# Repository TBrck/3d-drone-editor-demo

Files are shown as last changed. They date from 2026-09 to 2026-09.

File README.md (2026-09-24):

# AeroFrame X1

A 450 mm quadcopter airframe, designed parametrically in Python and published
as an interactive web page you can rotate, explode and take apart in a
browser.

**[Open the interactive model →](https://tbrockmeyer.github.io/3d-drone-editor-demo/)**
*(link goes live once GitHub Pages is enabled on this repo)*

---

## What this is

A mechanical design study. Every part was modelled in code on the OpenCASCADE
kernel; every mass, stress and safety factor shown on the site was computed
from that same geometry rather than typed in. Change one number in
[config.py](src/drone_demo/config.py) and the model, the bill of materials,
the drawings and the analysis all regenerate together.

The airframe is deliberately built from six different manufacturing processes,
one per part family, so the design decisions behind each are visible:

| Part | Process | Material |
|---|---|---|
| Motor mounts, arm clamps | CNC milling | Al 6061-T6 |
| Frame plates | CFRP sheet, CNC routed | 2 mm woven laminate |
| Arm tubes | Pultruded stock, cut to length | CFRP |
| ESC brackets, battery tray | Sheet metal, laser + press brake | Al 5052-H32 |
| Landing legs | FDM 3D printing | PA12-CF |
| Feet, propellers | Injection moulding | TPU / PA6-GF30 |

## What the site shows

- The full assembly, orbitable, with an exploded-view slider and a section plane
- Click any part for its material, process, mass, tolerances and the reasoning behind its design
- A bill of materials with the mass breakdown
- Hand calculations — arm root bending, tip deflection, first natural frequency, clamp slip, bolt shear, landing impact — each shown with its formula and inputs
- Linear-static FEA results overlaid on the model, with a mesh convergence check and a plain statement of the method's limits
- Dimensioned drawings and downloadable STEP files

---

## Quick start — just look at it

You do **not** need to rebuild anything to view the model: the generated
`drone.glb`, `manifest.json`, drawings and STEP files are already committed
under `web/assets/`. All you need is Python 3.11 to serve them (the CAD
kernel is not required just to view the page — only to change it).

```powershell
.\scripts\bootstrap.ps1                  # one-time: creates .venv311, installs everything
python -m drone_demo serve               # serves web/ and opens it in your browser
```

`bootstrap.ps1` also activates nothing on its own — after it finishes, either
activate the venv (`.venv311\Scripts\Activate.ps1`, after which plain `python`
means the venv's Python) or call the interpreter directly every time:

```powershell
.venv311\Scripts\python.exe -m drone_demo serve
```

Both `python -m drone_demo <command>` and `python src/drone_demo <command>`
work identically — pick whichever you find more natural. `serve` opens
`http://127.0.0.1:8000` in your default browser automatically; pass
`--port 8080` or `--no-open-browser` if you want something different.

> **The page must be served over HTTP.** Double-clicking `web/index.html`
> will not work — it loads `manifest.json` and `drone.glb` via `fetch()` and
> uses ES modules, both of which browsers block on `file://` URLs.

---

## Making a change

Everything downstream is *derived*, never hand-edited. The one-way flow is:

```
config.py + materials.py     the specification — every dimension, one file
        |
        v
parts/*.py                   geometry builders — one file per sub-assembly
        |
        v
assembly.py                  where each part instance is placed, and how many
        |
        +--> analysis/       mass properties, hand calculations, FEA
        |
        v
export/                      writes drone.glb, manifest.json, SVG, STEP, DXF
        |
        v
web/                          the site — reads manifest.json, has no design data of its own
```

That last point matters: the browser never contains a dimension, a mass or a
material property directly. It only reads whatever `export/manifest.py`
wrote. So changing the design is always the same three steps: **edit the
Python, regenerate the assets, refresh the browser.**

### 1. Change a dimension

Every physical dimension in the airframe lives in one file:
[`src/drone_demo/config.py`](src/drone_demo/config.py). It's a set of frozen
dataclasses, one per sub-assembly, assembled into a single `SPEC` object that
the rest of the codebase imports and never mutates.

For example, to make the vehicle bigger, open `config.py` and find the
`Airframe` dataclass near the top:

```python
@dataclass(frozen=True)
class Airframe:
    ...
    wheelbase_mm: float = 450.0   # <- change this to 550.0, say
```

Then rebuild just the geometry (fast — tens of seconds, no FEA) and refresh
the already-open browser tab:

```powershell
python -m drone_demo build
```

If `serve` is still running in another terminal, a browser refresh is all you
need — `build` overwrites `web/assets/drone.glb` and `manifest.json` in
place.

Other dataclasses worth knowing:

| Dataclass | Controls |
|---|---|
| `Airframe` | wheelbase, arm count, arm angle, target mass, thrust target |
| `ArmTube`, `MotorMount`, `ArmClamp` | the arm assembly |
| `FramePlate`, `Standoff` | the top/bottom plates and how they're spaced |
| `LandingLeg`, `LandingFoot` | the printed leg and moulded foot |
| `EscBracket`, `BatteryTray` | the two sheet-metal parts |
| `Motor`, `Propeller`, `Battery` | purchased-item envelopes (for mass and clearance only — not designed here) |

A few dimensions are cross-checked by tests (for example `ArmTube.length_mm`
has to keep the arm's tube+collar geometry landing exactly on the wheelbase
radius). If you change something load-bearing, run `pytest` afterward (see
below) — it will tell you exactly which geometric consistency check broke,
rather than letting the model silently go out of tolerance.

### 2. Change a shape

Dimensions alone only get you so far — actually changing *what a part looks
like* means editing its builder function in
[`src/drone_demo/parts/`](src/drone_demo/parts/). There's one file per
sub-assembly:

| File | Parts it builds |
|---|---|
| `arm.py` | arm tube, motor mount, split clamp halves |
| `frame.py` | top/bottom plates, standoffs |
| `landing.py` | landing leg, landing foot |
| `electronics.py` | ESC bracket, battery tray, motor/battery placeholder solids |
| `rotor.py` | propeller |
| `hardware.py` | screws |

Each part is a small, self-contained function that returns a
`build123d.Part`, built with build123d's `BuildPart`/`BuildSketch` context
managers (the same declarative style as most modern Python CAD kernels — see
[build123d's docs](https://build123d.readthedocs.io/) if you haven't used it
before). At the bottom of each file, one `register(PartDef(...))` call wires
the builder into the pipeline — that's the part's key, its name, which
material/process it uses, how many the assembly needs, and the design notes
shown in the viewer's detail panel. `src/drone_demo/parts/base.py` documents
every `PartDef` field.

To **add a brand-new part**: write a builder function, `register()` it with
a new unique key, and import the module (for its side effect of calling
`register()`) from [`parts/__init__.py`](src/drone_demo/parts/__init__.py).
Nothing else in the pipeline needs to know — mass, BOM, drawings and the
viewer all discover parts by walking the registry.

### 3. Change where a part is placed

How many instances of a part exist, and where each one sits in the assembly,
is decided in [`assembly.py`](src/drone_demo/assembly.py) — not in the part's
own builder, which only ever describes the part in its own local coordinate
frame. If you add a part and it isn't showing up anywhere (or four of
something show up stacked on top of each other), this is the file to look at.

### 4. Rebuild and check your work

```powershell
python -m drone_demo build       # geometry only -> drone.glb + manifest.json (fast: iterate here)
python -m drone_demo analyse     # print mass properties + hand calcs to the console
python -m drone_demo all         # full pipeline: geometry, FEA, drawings, downloads, manifest (slow: a few minutes)
pytest                            # run the test suite (add -m "not slow" to skip the CAD-rebuild tests)
```

Run `build` while you iterate on a shape or dimension — it's the fast loop.
Run `all` once, right before you're done, since it's the only command that
regenerates *everything* the published page depends on (including the FEA
results and STEP downloads, which `build` intentionally skips because they
take minutes). `pytest` catches the two failure modes that are easy to
introduce by hand and hard to spot by eye: parts that now interfere in 3D,
and a "parametric" model that only actually builds at its default dimensions.

---

## Parts & assembly studio

A local, login-gated web app for creating **simple** new parts — box/
cylinder/sphere plus union/subtract/intersect and rigid transforms — and
placing them in the vehicle, either by dragging primitives in a 3D editor or
by hand-editing JSON. It's a separate tool from the published site: it needs
its own dependency and never ships to GitHub Pages.

```powershell
pip install -e ".[studio]"      # one-time: installs Flask
python -m drone_demo studio     # http://127.0.0.1:5000, admin/admin (dummy — local only)
```

Everything a studio part needs — its shape, material, placement — lives in
[`src/drone_demo/custom_parts.json`](src/drone_demo/custom_parts.json), a
plain JSON file. The studio UI is one way to edit it; hand-editing the file
directly works exactly the same, since both go through the same
[`build_from_shape_spec`](src/drone_demo/parts/custom.py) interpreter — there
is no separate "studio path" a hand-written part takes that produces a
different result. A studio part becomes an ordinary `PartDef`/`Instance` the
moment `custom_parts.json` has an entry for it, so it flows through mass
properties, the BOM, `manifest.json` and STEP export with no other code
involved.

This complements, not replaces, the parametric workflow above: anything
needing a fillet, a loft, a chamfer or a sweep — most of what's actually on
this airframe — stays a hand-written `build123d` function, the same as
today. The studio is for the simple stuff (a spacer, a mounting plate, a
bracket) you'd rather sketch than write a `BuildPart` block for.

A saved change updates `custom_parts.json` immediately, but the read-only
assembly shown behind the part you're editing, and the actual published
site, only update when you rebuild — either the studio's own "Rebuild"
button, or `python -m drone_demo build` from the terminal.

**Honestly not production-grade, on purpose**: the login is a single
hardcoded credential (`admin`/`admin`), checked by one function
([`drone_demo.studio.auth.verify_credentials`](src/drone_demo/studio/auth.py))
that everything else calls through — swapping in a real user store later is
a one-function change, not a rewrite. It's fine as-is because the studio only
ever binds to `127.0.0.1`, exactly like `serve`.

---

## Project layout

```
src/drone_demo/
  config.py          every dimension — the one file to edit for a resize
  materials.py        material properties (density, yield) and process metadata
  custom_parts.json     studio-authored parts — see "Parts & assembly studio" above
  parts/               one module per sub-assembly; each part is a PartDef
    base.py            the PartDef contract every part module satisfies
    custom.py           reads custom_parts.json, interprets shape JSON into build123d
  assembly.py          instance placement: how many of each part, and where
  analysis/
    mass_properties.py  mass, centre of gravity, inertia
    statics.py          closed-form hand calculations
    fea.py               gmsh meshing + scikit-fem finite element solves
  export/
    gltf.py              writes drone.glb for the web viewer
    manifest.py          writes manifest.json, the contract with web/
    drawings.py           dimensioned SVG sheets + DXF flat patterns
    cad.py                STEP/STL downloads
  studio/                Flask app behind `python -m drone_demo studio` (needs the studio extra)
  cli.py                the `drone_demo` command line app
web/
  index.html, css/, js/  the static viewer (three.js) — reads manifest.json only
  vendor/                 vendored, pinned three.js (not from a CDN)
  assets/                  generated output: drone.glb, manifest.json, drawings/, downloads/, fea/
studio/
  templates/, static/     the studio's own frontend — deliberately not under web/,
                           since web/ is what ships to the public GitHub Pages site
docs/
  IMPLEMENTATION_PLAN.md  build order, specifications, acceptance criteria
tests/                    pytest suite — geometry, interference, manifest contract
```

## CLI reference

```powershell
python -m drone_demo --help     # full command list
python -m drone_demo parts      # list the part registry
python -m drone_demo check      # sanity-check every builder still runs
python -m drone_demo build      # geometry -> drone.glb + manifest.json (fast, for iteration)
python -m drone_demo analyse    # print mass properties and the hand calculations
python -m drone_demo fea        # finite element cases (slow, a few minutes)
python -m drone_demo drawings   # SVG sheets and DXF flat patterns
python -m drone_demo downloads  # STEP/STL/DXF download set
python -m drone_demo all        # everything above, in order, into one manifest
python -m drone_demo serve      # http://127.0.0.1:8000
python -m drone_demo studio     # http://127.0.0.1:5000 — parts & assembly studio, needs pip install -e ".[studio]"
```

---

## Troubleshooting

**The page loads (header and side panel look right) but the 3D viewport is
solid black.** This is almost always the browser's WebGL context, not the
generated model — nothing in `web/assets/` differs between a working and a
black viewport. Check, in order:
1. Open DevTools (F12) → Console while on the Model tab and look for a red
   error mentioning `WebGLRenderer` or `CONTEXT_LOST`. That error message is
   the actual cause.
2. In Chrome/Edge, open `chrome://gpu` (or `edge://gpu`) and check the
   "Graphics Feature Status" section for `WebGL`/`WebGL2`. If it says
   "Software only" or lists it as disabled, hardware acceleration is off —
   re-enable it under Settings → System, or check with IT if this is a
   managed machine (common on corporate/VDI images).
3. Hard-refresh (Ctrl+Shift+R) to rule out a stale cached `drone.glb` from
   before a rebuild.

**`ModuleNotFoundError` when running a command.** Every intra-package import
in `src/drone_demo` is a fully-qualified `drone_demo.xyz` absolute import, so
`python -m drone_demo ...`, `python src/drone_demo ...` and the installed
`drone-demo` console script all work identically — this only breaks if the
package isn't installed in your active interpreter. Re-run
`.\scripts\bootstrap.ps1`, or check `python -c "import drone_demo; print(drone_demo.__file__)"`
resolves to this repo's `src/drone_demo/`.

**Port 8000 already in use.** `python -m drone_demo serve --port 8080`.

---

## Documentation

- [docs/IMPLEMENTATION_PLAN.md](docs/IMPLEMENTATION_PLAN.md) — build order, specifications, acceptance criteria

## Limitations

Stated plainly, because a design study that oversells its analysis is worse
than one that has none:

- FEA is linear-static on first-order tetrahedra: a screening and comparison
  tool, not a certification analysis.
- Bolted joints are fixed restraints. No contact, preload or friction.
- Composites are treated as isotropic — reasonable for the tube in axial
  bending, wrong elsewhere.
- Endurance is a first-order energy estimate, good to perhaps 20 %.
- Nothing here has been built or flown.

## Licence

MIT.

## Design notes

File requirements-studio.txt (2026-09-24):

# Extra dependency for the parts & assembly studio (`python -m drone_demo
# studio`), pinned to the version installed and smoke-tested in .venv311
# (Python 3.11.7, Windows 11). Not part of requirements.txt: the studio is a
# local, login-gated authoring tool, not part of the published pipeline, so
# the core CAD/CLI workflow's dependency footprint stays untouched without
# this file. Install with:
#
#     .venv311\Scripts\python.exe -m pip install -r requirements.txt -r requirements-studio.txt
#     .venv311\Scripts\python.exe -m pip install -e ".[studio]"

flask==3.1.3

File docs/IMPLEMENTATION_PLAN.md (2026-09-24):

# AeroFrame X1 — implementation plan

This document is written to be handed to someone (or something) that will
write the code. The scaffolding, the specification, the part registry, the
engineering rationale and the file layout already exist in the repo. What is
missing is geometry, arithmetic and rendering.

Every stub in the codebase points back here with a step number. Every step
below states what to build, how to know it works, and what to avoid.

---

## 0. How to use this plan

**Read this first, then work milestone by milestone.** The milestones in
[§10](#10-milestones) are ordered so that something is visible on screen
early and stays working. Do not implement the whole pipeline before running
anything — the failure modes in CAD code are geometric, and geometric bugs
are found by looking.

**Rules that apply everywhere:**

1. **No hard-coded dimensions outside `config.py`.** If a number appears in a
   part module, it is a bug. The one exception is a genuinely universal
   constant (`math.pi`), and even then prefer a named constant.
2. **No design strings in JavaScript.** All display text comes from
   `manifest.json`. A number typed into the web layer stops matching the CAD
   the first time a parameter changes, and nothing will warn you.
3. **Units are mm, grams, newtons, MPa** throughout Python. The only unit
   conversion in the codebase is in `export/gltf.py`, which converts to
   metres because glTF requires it.
4. **Select CAD features by position, never by index.** `edges()[3]` works
   until a dimension changes and then silently fillets the wrong edge.
   Use `.filter_by()`, `.group_by(Axis.Z)`, `.sort_by()` with a geometric
   predicate.
5. **Run the tests after every part.** `pytest -m "not slow"` takes about
   four seconds and catches most parameter mistakes.
6. **When a stub's docstring and this document disagree, the docstring
   wins** — it is closer to the code.

---

## 1. Environment — already done and verified

`.venv311` exists and is provisioned. Python 3.11.7 on Windows. Every package
below installed cleanly and was smoke-tested end to end on this machine:

| Package | Version | Role |
|---|---|---|
| `build123d` | 0.11.1 | CAD kernel wrapper (pulls `cadquery-ocp-novtk` 7.9.3) |
| `trimesh` | 5.0.0 | mesh handling, GLB writing |
| `numpy` | 2.4.6 | arrays |
| `scipy` | 1.17.1 | sparse solver behind scikit-fem |
| `gmsh` | 4.15.2 | tetrahedral meshing; the wheel bundles the binary |
| `scikit-fem` | 12.0.2 | FE assembly and solve |
| `meshio` | 5.3.5 | `.msh` reader |
| `typer` / `rich` | 0.27.1 / 15.0.0 | CLI |
| `pytest` / `ruff` | 9.1.1 / 0.16.2 | tests, lint |

To rebuild from scratch: `.\scripts\bootstrap.ps1`.

**Verified working right now:** `python -m drone_demo parts` lists 16 part
types / 103 items, and `pytest tests/test_registry.py` passes 53 checks.

Still to do once: `.\scripts\fetch_vendor.ps1` to vendor three.js 0.185.1
into `web/vendor/`.

---

## 2. Architecture

```
config.py          every dimension, as frozen dataclasses. SPEC is the only instance.
materials.py       material properties + manufacturing processes with their design rules.
      |
parts/             base.py defines PartDef; six modules register 16 parts.
      |            Builders return geometry in the part's OWN local frame.
      |            They know nothing about where the part ends up.
assembly.py        places Instances in vehicle coordinates. Owns ALL positioning.
      |            Also owns explode direction and rank per instance.
      |
      +-- analysis/    mass_properties (CAD-derived), statics (closed form), fea (gmsh+skfem)
      |
export/            mesh.py  tessellation -> trimesh
                   gltf.py  scene -> drone.glb          (owns mm->m and Z-up->Y-up)
                   manifest.py  the JSON contract
                   drawings.py  SVG sheets + DXF flat patterns
                   cad.py       STEP / STL downloads
      |
web/               static site. Reads manifest.json and nothing else.
```

**The invariant that everything hangs on:**

```
glTF node name  ==  manifest instance node_id  ==  f"{part_key}__{index}"
```

Click-to-select, isolate, explode, colour-by-process and the FEA overlay are
all lookups on that string. `export/manifest.py::validate()` must check it
against the node names actually present in the `.glb`. When a click selects
nothing in the browser, check this before anything else.

---

## 3. Part geometry

Each builder returns a `build123d.Part` positioned at its own natural datum.
Read the docstring in the stub — it specifies the geometry feature by feature.
This section adds only what the docstrings do not cover.

### 3.1 `parts/arm.py::build_arm_tube`

Trivial, and therefore the right place to establish the pattern. Get the
local frame convention right here (axis along +X, starting at the origin) and
the rest of the arm follows.

**Done when:** volume matches `π/4·(D²−d²)·L` to within the chamfer volume,
and `test_every_part_builds` passes for it.

### 3.2 `parts/arm.py::build_motor_mount`

The hardest single part, and the one most worth the effort — it is the part a
reviewer will zoom in on.

Order of operations matters. Build collar and plate as separate solids, fuse
them, *then* fillet the junction. Filleting before the fuse gives an edge
that no longer exists after it.

For the fillet edge selection, find the edges shared between the collar and
plate faces geometrically rather than by index:

```python
junction = bp.edges().filter_by(GeomType.CIRCLE).group_by(Axis.Z)[-1]
fillet(junction, radius=mm.fillet_mm)
```

Fillets are the most common OCCT failure. If one throws, reduce the radius
and check that adjacent features are not closer to the edge than the radius —
that is nearly always the cause.

**Done when:** the part builds, is a single solid, has visible fillets and
chamfers, and its bolt pattern matches `MotorMount.bolt_pattern_a/b_mm`.

### 3.3 `parts/arm.py::_clamp_half`

One function, branching on `is_upper`. Do not split it into two — a change to
the tube diameter has to move both halves together or the joint opens up.

The 0.4 mm gap between the halves at nominal is deliberate and must be in the
model: it is what guarantees the bolts still have travel when the tube is at
its lower diameter tolerance.

### 3.4 `parts/frame.py`

The plate outline is a chamfered square; build it with `Polygon` or a
rectangle plus corner cuts, whichever reads more clearly. `standoff_circle_mm`
and the four arm bolt groups are `PolarLocations` and `Locations` patterns.

Handle `lightening_hole_dia_mm == 0` without failing — the config comment
promises it works.

### 3.5 `parts/landing.py`

The leg's tapered fuse section must be a continuous loft or sweep, not
stacked boxes. A stepped section puts the stress concentration at the step
instead of in the middle of the fuse, which defeats the design intent the
part exists to demonstrate.

The 45° overhang constraint is checked by `test_printed_leg_has_no_unprintable_overhang`.
Build the geometry with that test in mind rather than fixing it afterwards.

### 3.6 `parts/electronics.py`

Model the bends as real radii. The whole point of these two parts is showing
sheet metal literacy, and a folded bracket drawn with sharp corners says the
opposite. Sweeping the folded profile along the part width is the simplest
approach that gives true bend radii.

`flat_pattern_length()` uses the K-factor method, K = 0.38:

```
BA_90 = (π/2) · (r + K·t)
developed = leg_a + leg_b + BA_90        # legs measured to the bend tangents
```

`test_sheet_metal_thickness_is_uniform` cross-checks this against the CAD
volume, so the two have to agree.

### 3.7 `parts/rotor.py::build_propeller`

Loft through 6–8 twisted sections. The pitch law is three lines and is what
makes the prop look right:

```python
beta = math.atan2(pitch_mm, 2 * math.pi * r)     # radians from the rotor disc
```

Keep the section count low — 8 sections tessellate to a few thousand
triangles and look identical to 30.

### 3.8 `parts/hardware.py::build_screw`

Plain cylindrical shank, cosmetic hex socket, no helical thread. `functools.partial`
is already wired up for the two lengths.

---

## 4. Assembly (`assembly.py`)

Implement in this order: `translation` → `rotation_z` → `compose` →
`build_arm` → `build_frame` → `build_assembly`.

**Transform convention:** row-major 4×4, and `compose(a, b)` means "apply `a`,
then `b`". Write that down in the code and hold to it. A reversed
multiplication order is the single most likely source of a wrong-looking
assembly, and it is hard to spot because most parts sit near the origin.

**Build each arm along +X, then rotate once.** Do not place parts directly at
45° — the trigonometry ends up copied into a dozen places and one of them
will be wrong.

**Explode vectors.** Choose them so the explosion reads as a disassembly
sequence a fitter would actually perform:

| Instance | direction | rank |
|---|---|---|
| propeller | +Z | 4 |
| motor | +Z | 3 |
| motor screws | +Z | 5 |
| motor mount | +X (along the tube) | 2 |
| arm tube | +X | 1 |
| clamp upper | +Z | 2 |
| clamp lower | −Z | 2 |
| landing leg / foot | −Z | 2 / 3 |
| ESC bracket | −Z | 1 |
| top plate | +Z | 1 |
| battery / tray | −Z | 2 / 1 |
| frame plates, standoffs | ±Z | 1 |

Higher rank travels further, so outer parts clear the ones beneath them
instead of passing through. Check this visually at explode = 1.0; if any two
parts intersect on the way out, the ranks are wrong.

**Determinism.** Same code, same instance order, every run — otherwise the
`.glb` changes on every rebuild and git diffs become useless.

**Done when:** `build_assembly()` returns ~103 instances, every `node_id` is
unique, and rendering it shows a quadcopter rather than an exploded parts bin.

---

## 5. Analysis

### 5.1 `analysis/mass_properties.py`

Cache the built geometry. `part_mass`, the exporter and the FEA driver all
want the same solids, and each builder call is a full OCCT rebuild:

```python
@functools.lru_cache(maxsize=None)
def _geometry(key: str): return get(key).builder()
```

Verified available: `part.volume` (mm³) and `part.center(CenterOf.MASS)`.

**The centre of gravity must be summed over instances, not part types.** Four
arms at four angles have four different transforms, and each part's local
centre of mass has to be transformed into vehicle coordinates first. Getting
this wrong produces a CoG at the origin — which looks plausible and is wrong.

Report `cog_offset_from_rotor_axis_mm` explicitly. On a multirotor that
number decides whether the aircraft can trim level, and it is the first thing
an experienced reviewer looks for.

Purchased parts (`material_key == "cots"`) use `mass_override_g`. This is
already enforced by `test_purchased_parts_have_a_mass_override`.

### 5.2 `analysis/statics.py`

Every stub carries its formula. Points worth restating:

- **`arm_root_bending`** — take the cantilever length as free tube length
  plus half the motor mount collar. A clamp does not restrain a tube
  perfectly at its face, and assuming it does under-predicts the moment.
- **`arm_tip_deflection`** — the allowable is L/150, a *stiffness* criterion.
  State the basis in `note`; an allowable with no stated basis is just a number.
- **`arm_first_mode_hz`** — the only check whose failure would not show up in
  any static analysis, which is exactly why it belongs in the report.
- **`clamp_slip`** — the nut factor K = 0.20 is uncertain by roughly ±30 %.
  Say so. This check has to be confirmed by test and claiming otherwise
  oversells it.
- **`landing_leg_impact`** — knock the printed material's allowable down to
  60 % for layer adhesion and say that you did. Using an isotropic datasheet
  value for a printed part is the classic route to a confident wrong answer.
  **This check is expected to show the lowest safety factor on the vehicle.**
  That is the design intent, and the report has to present it that way or it
  reads as an oversight.

`Check.safety_factor` is `allowable / applied`; `passes` is
`safety_factor >= target_sf`.

### 5.3 `analysis/fea.py`

The whole chain is verified working on this machine. Reference implementation
of the solve core, taken from the smoke test that ran successfully:

```python
import gmsh, skfem, numpy as np
from skfem.models.elasticity import linear_elasticity, lame_parameters, linear_stress
from skfem.helpers import sym_grad

# --- mesh -------------------------------------------------------------
gmsh.initialize()
try:
    gmsh.option.setNumber("General.Terminal", 0)
    gmsh.model.add(part_key)
    gmsh.model.occ.importShapes(step_path)
    gmsh.model.occ.synchronize()
    gmsh.option.setNumber("Mesh.CharacteristicLengthMax", size_mm)
    gmsh.option.setNumber("Mesh.CharacteristicLengthMin", size_fine_mm)
    gmsh.model.mesh.generate(3)
    gmsh.write(msh_path)
finally:
    gmsh.finalize()          # ALWAYS. gmsh keeps global state.

mesh = skfem.Mesh.load(msh_path)          # -> MeshTet1

# --- solve ------------------------------------------------------------
basis = skfem.Basis(mesh, skfem.ElementVector(skfem.ElementTetP1()))
lam, mu = lame_parameters(E_mpa, nu)
K = linear_elasticity(lam, mu).assemble(basis)
D = basis.get_dofs(lambda x: x[0] < x_min + 1e-6)      # restraint predicate
f = basis.zeros()
f[basis.get_dofs(load_predicate).nodal["u^3"]] = force_n / n_loaded_nodes
u = skfem.solve(*skfem.condense(K, f, D=D))

# --- von Mises --------------------------------------------------------
C = linear_stress(lam, mu)
s = C(sym_grad(basis.interpolate(u)))
vm = np.sqrt(0.5 * ((s[0,0]-s[1,1])**2 + (s[1,1]-s[2,2])**2 + (s[2,2]-s[0,0])**2
                    + 6*(s[0,1]**2 + s[1,2]**2 + s[0,2]**2)))
```

**Units:** E in MPa and mesh in mm gives forces in N and displacements in mm.
Keep everything in that system and no conversion is needed anywhere.

**Always `gmsh.finalize()` in a `finally`.** A leaked session makes the *next*
mesh inherit the previous model's settings — producing a plausible wrong
answer rather than an error.

**Local refinement:** use a `Distance` + `Threshold` mesh field around the
fillet edges. Dropping the global size to 0.6 mm on the motor mount gives
hundreds of thousands of elements and takes minutes.

**Convergence is not optional.** Run each case twice, at `mesh_size_mm` and at
half of it, and record the relative change in peak stress. Above ~10 % means
not converged, and the report must show the number. A stress plot with no
convergence check is decoration.

**Report the peak from element values,** not from vertex-averaged ones.
Averaging onto vertices smooths the maximum away, which flatters the result.
Use vertex averaging for the colour map only.

Cross-check `tube_root_bending` against `statics.arm_root_bending`. They
should agree within about 10 %. If they do not, one of them is wrong, and
experience says it is usually the FE model — check the restraint first.

**Colour ramp:** viridis or blue-white-red. Not a rainbow. Rainbow ramps
invent boundaries that are not in the data and are why so many FEA plots
mislead. The CSS legend gradient in `style.css` is already viridis; match it.

---

## 6. Export

### 6.1 `export/mesh.py`

```python
verts, tris = part.tessellate(tolerance=0.06, angular_tolerance=0.25)
# verts: list[build123d.Vector], tris: list[tuple[int,int,int]]
V = np.array([(v.X, v.Y, v.Z) for v in verts])
F = np.array(tris)
m = trimesh.Trimesh(vertices=V, faces=F, process=False)
m.merge_vertices()
```

Two things learned from testing this:

- `tessellate` emits vertices **per face**, so seams carry duplicates and the
  mesh reports as non-watertight until `merge_vertices()` runs. That call
  typically removes 30–50 % of the vertices and is what makes smooth-shading
  normals come out right across a fillet.
- Pass `process=False` to the constructor. Trimesh's default processing welds
  with its own tolerance and will merge across a sharp edge, rounding off the
  chamfers that were the point of the part.

### 6.2 `export/gltf.py`

Verified: `Scene.add_geometry(mesh, node_name=..., transform=...)` round-trips
node names through GLB intact, and `PBRMaterial` survives export.

```python
mesh.visual = trimesh.visual.TextureVisuals(
    material=trimesh.visual.material.PBRMaterial(
        name=material.key,
        baseColorFactor=[r, g, b, 1.0],
        metallicFactor=material.metalness,
        roughnessFactor=material.roughness))
scene.add_geometry(mesh, node_name=instance.node_id, transform=T)
blob = scene.export(file_type="glb")
```

**This module owns both conversions, and nothing else does:**
mm → m (`gltf_scale = 0.001`) and Z-up → Y-up (−90° about X). Bake them into
the scene root transform. Baking them into the CAD would corrupt the STEP
exports; doing it in the viewer would misplace every annotation.

**Share geometry across instances.** Cache the mesh per part key and reuse it
with four transforms for the four arms — it cuts the file to roughly a third.

Warn loudly above `triangle_budget` (900 k). A 40 MB glb makes the page
useless on a phone, and someone opening this link on a phone is a realistic
scenario worth protecting.

### 6.3 `export/manifest.py` — the schema

```jsonc
{
  "meta": {
    "schema_version": "1.0",       // viewer refuses an unknown major version
    "name": "AeroFrame X1",
    "revision": "A",
    "built_at": "2026-08-13T10:00:00Z",   // from git commit date, NOT now()
    "git_commit": "b180b79",
    "tool_versions": { "build123d": "0.11.1", "python": "3.11.7" },
    "scene": { "triangles": 412000, "nodes": 103,
               "bbox_min_m": [-0.24,-0.03,-0.24], "bbox_max_m": [0.24,0.09,0.24] }
  },

  "parts": {
    "motor_mount": {
      "key": "motor_mount", "name": "Motor mount, machined",
      "material_key": "al6061", "process_key": "cnc",
      "quantity": 4, "critical": true,
      "volume_mm3": 12450.0, "unit_mass_g": 33.6, "total_mass_g": 134.4,
      "mass_is_override": false,
      "local_com_mm": [0.0, 0.0, 4.2],
      "summary": "…", "design_notes": ["…"],
      "annotations": [{ "title":"…", "body":"…", "at_mm":[0,0,14], "kind":"interface" }],
      "drawing": "drawings/motor_mount.svg",
      "step": "downloads/motor_mount.step"
    }
  },

  "instances": [
    { "node_id": "motor_mount__0", "part_key": "motor_mount", "group": "arm_0",
      "transform_mm": [[…4×4 row-major…]],
      "explode_dir": [1,0,0], "explode_rank": 2 }
  ],

  "materials": { "al6061": { …copy of the Material dataclass… } },
  "processes": { "cnc":    { …copy of the Process dataclass… } },

  "bom": {
    "rows": [ { "part_key":"battery", "qty":1, "unit_mass_g":530.0,
                "total_mass_g":530.0, "mass_fraction":0.36 } ],
    "total_mass_g": 1472.3
  },

  "analysis": {
    "mass": { "total_mass_g":1472.3, "cog_mm":[0.0,0.0,12.4],
              "cog_offset_from_rotor_axis_mm":0.8,
              "inertia_g_mm2":[…], "structural_fraction":0.31 },
    "performance": { "thrust_to_weight":2.85, "hover_throttle":0.35,
                     "hover_endurance_min":18.2, "disc_loading_n_m2":28.4 },
    "checks": [
      { "key":"arm_root_bending", "title":"Arm tube root bending",
        "formula":"sigma = M*c/I,  M = F*L,  I = pi/64*(D^4-d^4)",
        "inputs": { "F":[10.3,"N"], "L":[165.0,"mm"], "D":[16.0,"mm"], "d":[13.0,"mm"] },
        "applied":41.2, "allowable":1200.0, "unit":"MPa",
        "safety_factor":29.1, "target_sf":2.0, "passes":true, "note":"…" }
    ],
    "fea": [
      { "key":"mount_max_thrust", "part_key":"motor_mount", "title":"…",
        "max_von_mises_mpa":86.4, "yield_mpa":276.0, "safety_factor":3.19,
        "max_displacement_mm":0.042, "nodes":48210, "elements":210433,
        "convergence_delta":0.061, "solve_seconds":14.2,
        "peak_location_mm":[0,6.2,5.1],
        "result_glb":"fea/mount_max_thrust.glb",
        "legend": { "min_mpa":0.0, "max_mpa":86.4, "ramp":"viridis" },
        "restraint":"…", "loading":"…" }
    ],
    "limitations": ["Linear-static, first-order tetrahedra…", "…"]
  },

  "story": [ { "key":"overview", "title":"…", "body":"…",
               "isolate":[], "explode":0.0, "camera":{…} } ],

  "downloads": { "Assembly STEP":"downloads/aeroframe_x1_assembly.step" }
}
```

`validate()` must check, at minimum:

- every `instance.part_key` resolves in `parts`
- every `material_key` / `process_key` resolves
- every `node_id` is unique **and the set matches the node names actually in
  `drone.glb`** — load it back with `trimesh.load(..., force="scene")` and
  compare `scene.graph.nodes_geometry`
- every referenced path exists on disk
- BOM total equals the mass report total to within 0.1 g
- every `story.isolate` entry names a real part key

Run it in the test suite *and* at the end of the build. A manifest naming a
node the glb does not contain gives a viewer that fails silently on click,
which is close to undebuggable from the browser side.

Serialise with `indent=2`, `sort_keys=False`, and take the timestamp from the
git commit date — not `datetime.now()`, or every rebuild produces a diff even
when nothing changed.

### 6.4 `export/drawings.py`

Verified working:

```python
visible, hidden = part.project_to_viewport(
    viewport_origin=(100, -100, 80), viewport_up=(0, 0, 1))
svg = ExportSVG(scale=2)
svg.add_layer("visible", line_weight=0.4)
svg.add_layer("hidden", line_weight=0.2, line_type=LineType.ISO_DASH)
svg.add_shape(visible, layer="visible")
svg.add_shape(hidden, layer="hidden")
svg.write(path)
```

build123d draws geometry, not dimensions. Compose dimension lines, arrows and
text into the SVG afterwards, driven by the declarative `dimension_set()`
data. Hand-placing dimensions in markup does not survive the first parameter
change.

**Dimension what is functional**, not what is convenient: bore diameter and
its fit, bolt pattern, thickness under the motor face. A drawing that
dimensions every edge tells a machinist nothing about what matters.

Sheet is A3 landscape, first-angle projection, and the title block must say
so. Pull material and mass from the manifest so the drawing can never
disagree with the model. The notes block carries the process design rules
straight out of `materials.py` — that is the part of the drawing that shows
process understanding.

DXF flat patterns via `ezdxf` (already installed as a build123d dependency),
with bend lines on their own layer marked with direction and angle.

### 6.5 `export/cad.py`

STEP for everything manufactured — it is what opens in SolidWorks as solid
geometry. Set each child's `label` to its `node_id` when building the assembly
`Compound` so it imports as a named tree rather than 60 anonymous bodies.
STL for the printed parts. Skip purchased parts.

---

## 7. CLI (`cli.py`)

`serve`, `parts` and `check` already work. Implement `build`, `analyse`,
`fea`, `drawings`, `downloads`, and `all`.

Each command prints a rich summary table — part count, instance count,
triangle count, file size, total mass, elapsed time. `all` runs everything in
order with `--skip-fea` for fast iteration.

`build` should take under 60 s. If it does not, the tessellation tolerance or
the propeller loft section count is the reason.

---

## 8. Web

Run `.\scripts\fetch_vendor.ps1` first.

### 8.1 `js/main.js`

Fetch `manifest.json`, check `meta.schema_version` major against
`SUPPORTED_SCHEMA_MAJOR`, refuse to start on a mismatch with a clear message.
Stream the glb with GLTFLoader's `onProgress` into the loader bar. Then
`createViewer` → `mountUI` → `renderReports` → remove the loader → restore
state from `location.hash`.

Deep links are worth getting right: `#part=motor_mount&explode=60` should
reproduce a view exactly. That is what makes the page linkable in an
application email, which is the whole point of building it.

### 8.2 `js/viewer.js`

The stub lists the full API and the implementation notes. The ones that will
cost time if missed:

- **Lighting:** hemisphere fill + key directional with shadows + rim, plus
  `RoomEnvironment` for reflections. A single directional light makes
  machined aluminium read as flat grey plastic and undoes the PBR work.
- **Section plane:** set `material.side = THREE.DoubleSide` on clipped
  materials, or the cut face renders as a hole and the model looks broken
  rather than sectioned.
- **Isolate:** fade others to opacity 0.06 rather than hiding them. A ghost of
  the surrounding structure is what makes an exploded sub-assembly readable;
  hide it and parts float in space with no reference.
- **Highlight:** boost emissive and restore the original on deselect. Do not
  replace the material — that loses the identity the colour modes depend on.
- **Picking:** walk `object.parent` up until the name matches a manifest
  `node_id`; glTF import nests meshes below the named node.
- `setPixelRatio(Math.min(devicePixelRatio, 2))`.

### 8.3 `js/ui.js`

Tree grouped by `instance.group` then `part_key`, so an arm shows one row per
part rather than four identical ones. Detail card from `manifest.parts[key]`.
Sliders throttled through `requestAnimationFrame`. Story steps drive
`flyTo` + `isolate` + `setExplode`, and **exit the tour on any manual camera
input** — a guided tour that fights the user for the camera is worse than no
tour.

Hotspots are DOM elements positioned by projecting the annotation's world
point to screen space each frame: the text stays selectable, accessible and
crisp at any zoom. Hide a hotspot when its point faces away from the camera
or it appears to float through the model.

Keyboard: `E` explode, `X` isolate, `Esc` clear, arrows step the story. Give
the canvas a tabindex and a focus ring.

### 8.4 `js/report.js`

BOM sorted by total mass descending with a mass-share bar behind each row —
on a flying vehicle the mass breakdown is the headline result and a plain
table buries it.

Analysis view: one `.calc` card per check showing formula, inputs, applied vs
allowable, and the safety factor coloured by margin. **The formula is the
point of the card.** A reviewer who can follow the algebra can judge the
result; one shown only a number has to take it on trust.

Put the FEA limitations next to the FEA results, not only on the About page.
A caveat belongs beside the result it qualifies.

One number-formatting helper used everywhere. Mixed precision down a column
is the fastest way to make a report look careless.

---

## 9. Tests

`tests/test_registry.py` passes (53 checks). Implement the skipped tests in
`tests/test_geometry.py`, in this order of value:

1. **`test_no_interference_between_instances`** — bounding boxes to find
   candidate pairs, then real boolean intersections on those. This is the
   highest-value automated check in mechanical CAD and the one thing this
   pipeline does that eyeballing a render cannot. Keep intended
   interferences (press fits, clamp grip) in an explicit allow-list so a new
   clash still fails.
2. **`test_parametric_sweep_stays_valid`** — rebuild across wheelbase
   350–600 mm and tube OD 12–20 mm. Catches the fillet that only fits at
   nominal, which is by far the most common way a "parametric" model turns
   out not to be.
3. **`test_printed_leg_has_no_unprintable_overhang`** — face normals against
   the 45° limit. Makes the "prints without support" claim checkable.
4. `test_moulded_parts_have_draft`, `test_sheet_metal_thickness_is_uniform`,
   `test_parts_are_single_solids`.

Add `tests/test_manifest.py` running `validate()` against a freshly built
manifest, including the glb node-name cross-check.

---

## 10. Milestones

Ordered so something is visible early and stays working.

| # | Deliverable | Contains |
|---|---|---|
| **M1** | *A drone on screen* | §3.1–3.3 (arm parts), §4 assembly, §6.1–6.2 glb, minimal §8.1–8.2 viewer with orbit only |
| **M2** | *The whole vehicle* | §3.4–3.8 remaining parts, full assembly, interference test |
| **M3** | *Interactive* | §6.3 manifest, §8.3 UI — tree, detail card, explode, section, isolate, story |
| **M4** | *Numbers* | §5.1–5.2 mass + statics, §8.4 BOM and analysis views |
| **M5** | *Simulation* | §5.3 FEA, stress overlay, legend, convergence |
| **M6** | *Documentation* | §6.4 drawings, §6.5 STEP downloads, drawings view |
| **M7** | *Publish* | preview image, deep links, mobile pass, Pages enabled |

M1–M3 is already a strong portfolio piece. M4 is what makes it a *mechanical
engineering* portfolio piece rather than a graphics demo. Do not skip ahead to
M5 — a stress plot on an unvalidated model is worth less than a clean hand
calculation.

---

## 11. Known risks

| Risk | Where it bites | What to do |
|---|---|---|
| Fillet/chamfer operations fail in OCCT | §3.2, §3.3 | Reduce the radius; check for features closer to the edge than the radius. Fail loudly rather than skipping the fillet — a part that silently loses its fillets also loses its FEA validity. |
| Transform order reversed | §4 | Assert one known instance's world position against a hand-computed value in the test suite. |
| Triangle count explodes | §6.1–6.2 | Budget is 900 k. The propeller loft and the tessellation tolerance are the two levers. |
| gmsh global state leaks between cases | §5.3 | `finalize()` in a `finally`, always. |
| FEA disagrees with hand calc | §5.3 | Expected within 10 %. Beyond that, check the restraint first — over-constraint is the usual cause. |
| glb node names do not match the manifest | §6.2–6.3 | `validate()` cross-checks against the actual glb. Do not skip it. |
| Page opened as `file://` | §8 | Modules and `fetch` are blocked from `file://`. `python -m drone_demo serve` exists for exactly this and says so. |
| three.js version drift | §8 | Vendored and pinned at 0.185.1. Core and addons must move together. |
| Assets not rebuilt before publishing | §10 | The Pages workflow's `check-assets` step fails the build. |

---

## 12. Definition of done

- `python -m drone_demo all` runs clean from a fresh clone after `bootstrap.ps1`
- `pytest` passes, including the geometry tests
- `validate()` returns no problems
- The page loads in under 3 s on a normal connection and works on a phone
- Every part opens a detail card with material, process, mass and design notes
- Every calculation shows its formula and inputs
- Every FEA result shows its convergence delta and the method's limitations
- The STEP download opens in SolidWorks as a named assembly tree
- Nothing on the page claims more than the analysis supports

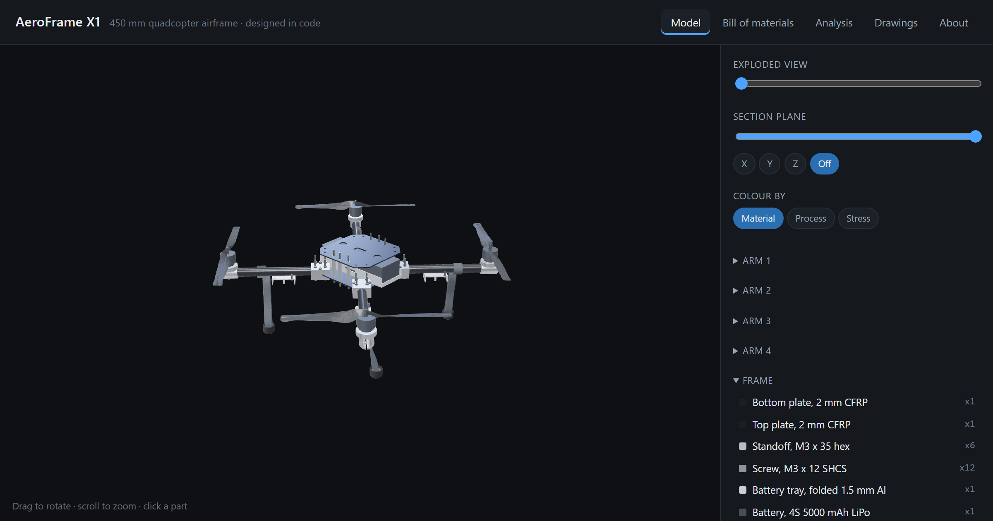
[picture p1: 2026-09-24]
web/assets/preview.png

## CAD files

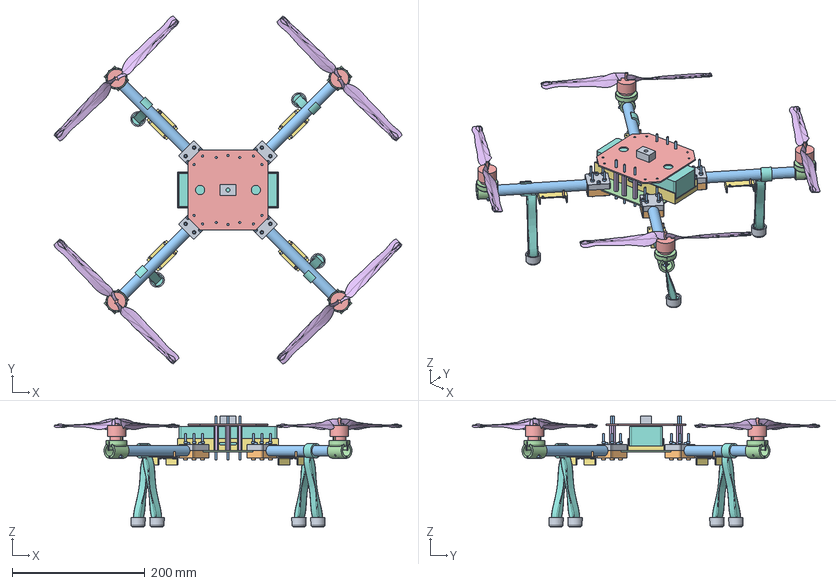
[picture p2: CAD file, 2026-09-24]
web/assets/downloads/aeroframe_x1_assembly.step
523.4 x 523.4 x 166.7 mm
arm_clamp_upper__3 x 4
arm_clamp_lower__3 x 4
arm_tube__3 x 4
motor_mount__3 x 4
motor__3 x 4
propeller__3 x 4
esc_bracket__3 x 4
landing_leg__3 x 4
landing_foot__3 x 4
screw_m3x8__23 x 24
screw_m3x12__39 x 40
bottom_plate__0
top_plate__0
standoff__5 x 6
battery_tray__0
battery__0
camera_mount_plate__0

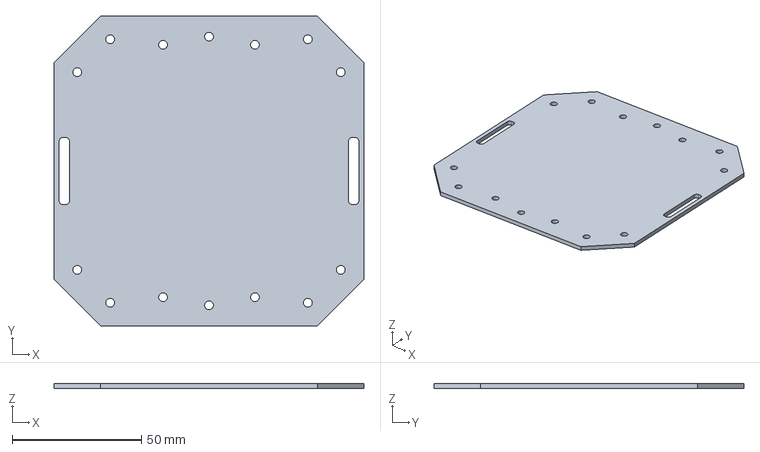
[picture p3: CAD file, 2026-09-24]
web/assets/downloads/bottom_plate.step
120.0 x 120.0 x 2.00 mm

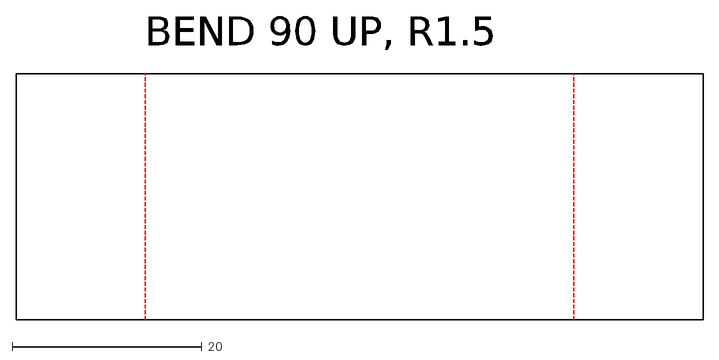
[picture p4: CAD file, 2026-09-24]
web/assets/drawings/esc_bracket_flat.dxf
BEND 90 UP, R1.5

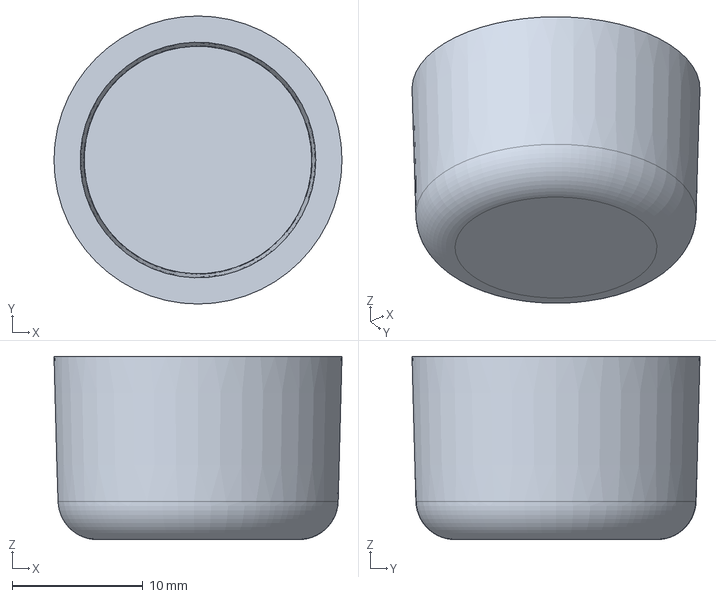
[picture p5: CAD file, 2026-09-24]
web/assets/downloads/landing_foot.step
22.0 x 22.0 x 14.0 mm

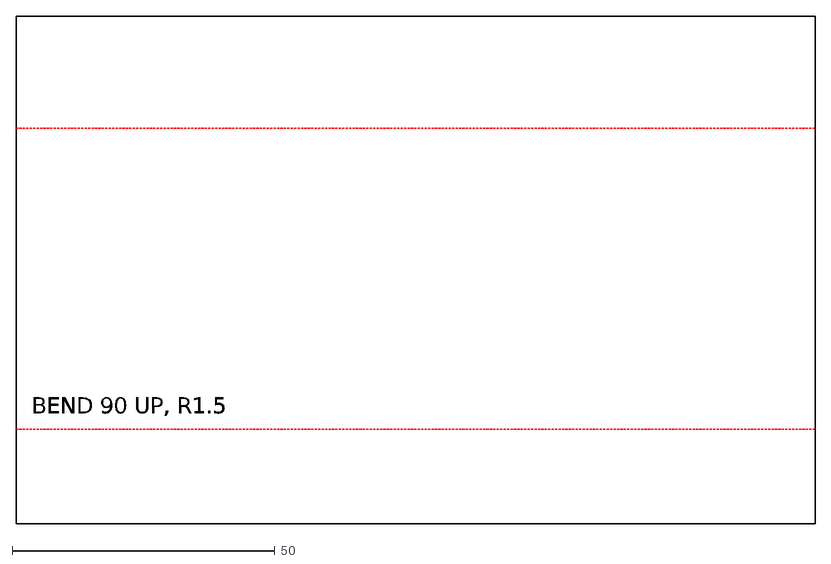
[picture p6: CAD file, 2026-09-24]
web/assets/drawings/battery_tray_flat.dxf
BEND 90 UP, R1.5

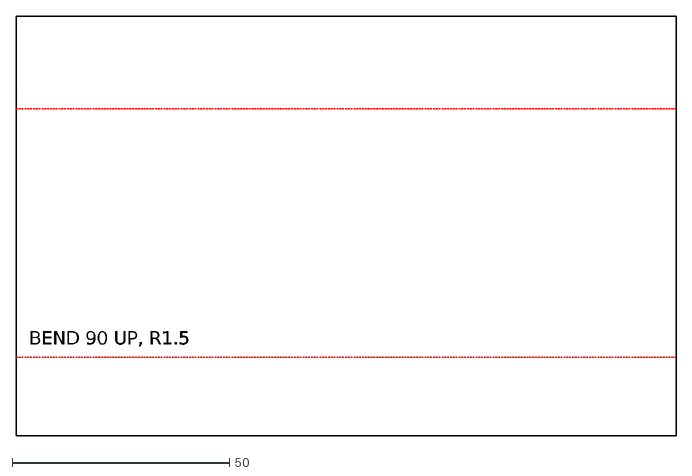
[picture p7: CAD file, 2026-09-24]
web/assets/downloads/battery_tray_flat.dxf
BEND 90 UP, R1.5

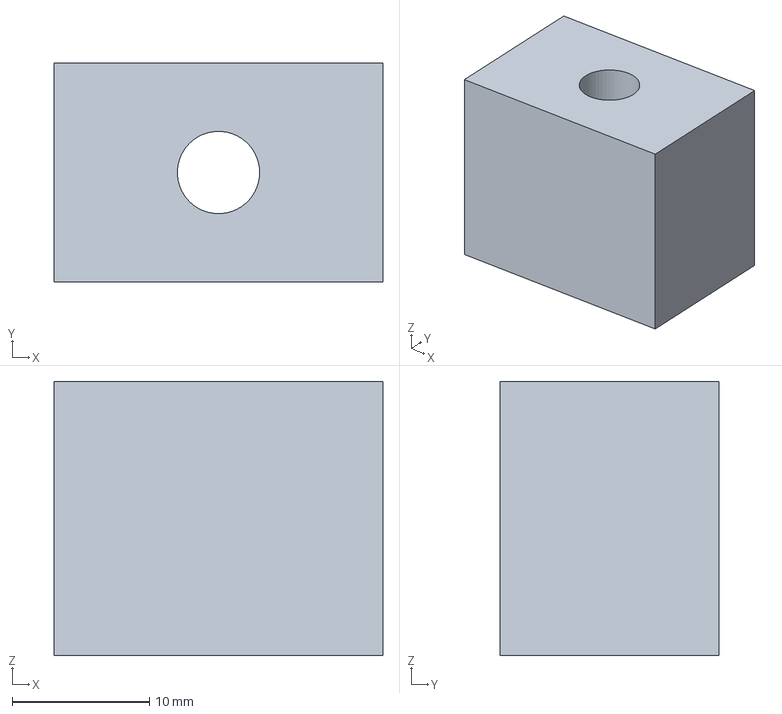
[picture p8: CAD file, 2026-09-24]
web/assets/downloads/camera_mount_plate.step
24.0 x 16.0 x 20.0 mm

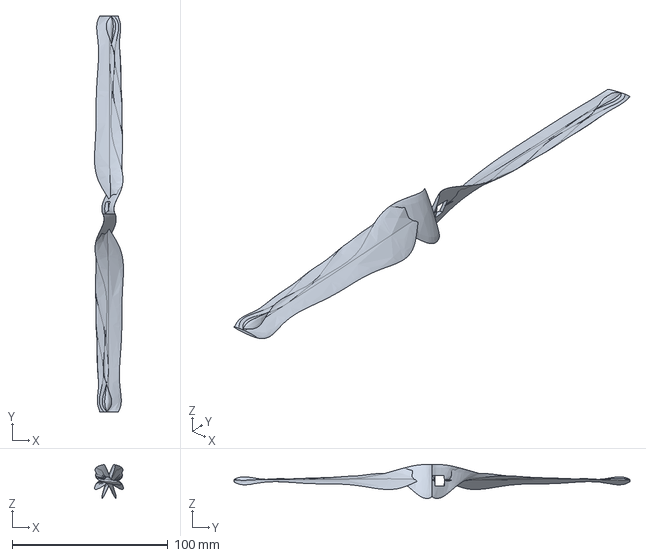
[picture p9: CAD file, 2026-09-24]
web/assets/downloads/propeller.step
18.6 x 254.0 x 21.8 mm

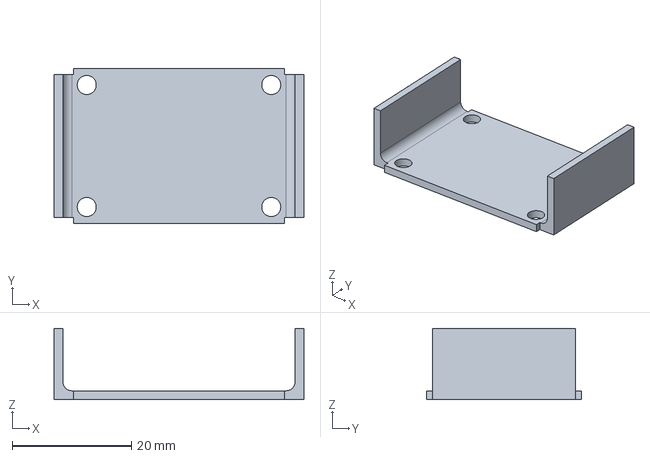
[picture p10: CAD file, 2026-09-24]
web/assets/downloads/esc_bracket.step
42.0 x 26.0 x 12.0 mm

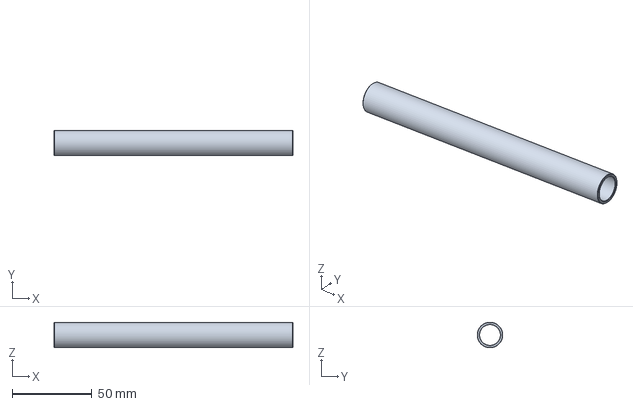
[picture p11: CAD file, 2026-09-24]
web/assets/downloads/arm_tube.step
150.0 x 16.0 x 16.0 mm

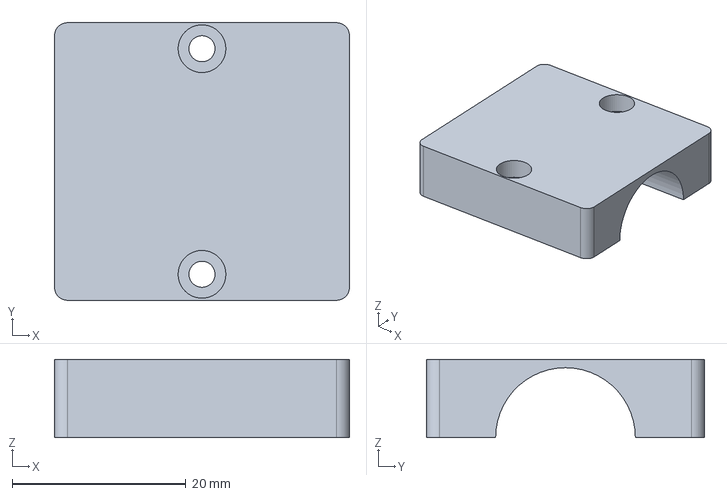
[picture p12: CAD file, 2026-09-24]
web/assets/downloads/arm_clamp_upper.step
34.0 x 32.0 x 9.00 mm

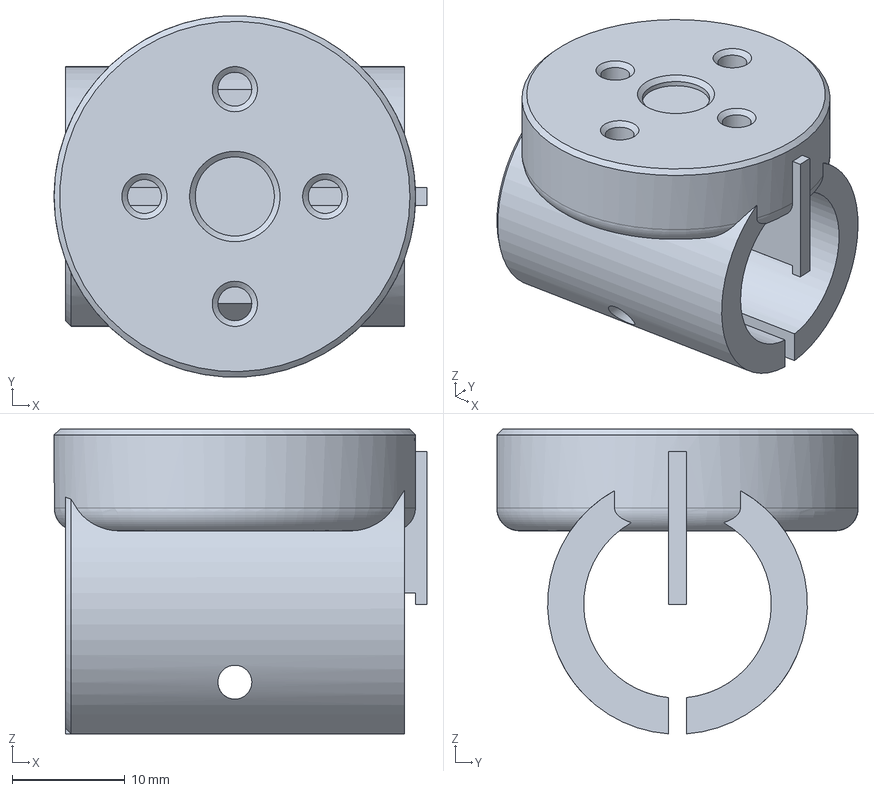
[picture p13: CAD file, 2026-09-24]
web/assets/downloads/motor_mount.step
33.0 x 32.0 x 27.0 mm

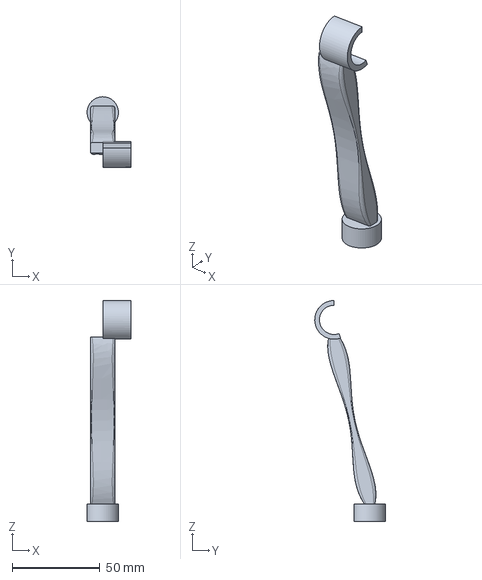
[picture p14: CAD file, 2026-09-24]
web/assets/downloads/landing_leg.step
24.9 x 40.1 x 125.7 mm

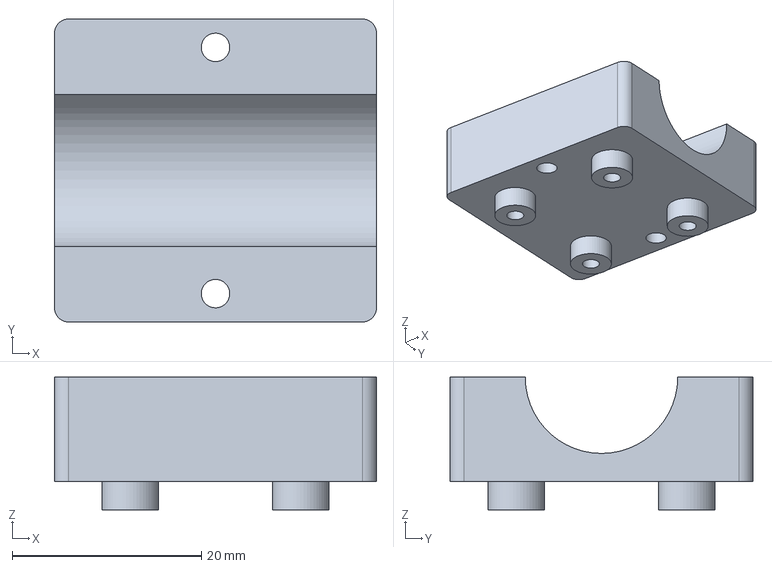
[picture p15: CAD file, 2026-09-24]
web/assets/downloads/arm_clamp_lower.step
34.0 x 32.0 x 14.0 mm

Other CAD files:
web/assets/downloads/top_plate.step
web/assets/downloads/esc_bracket_flat.dxf
web/assets/downloads/battery_tray.step
web/assets/downloads/landing_leg.stl

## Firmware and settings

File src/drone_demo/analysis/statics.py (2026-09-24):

"""Closed-form checks on the load path.

These are the calculations that would go on a design review slide: they are
quick, they are checkable by hand, and they are what sizes the parts. The FEA
in :mod:`.fea` exists to confirm them, not to replace them.

Every function returns a :class:`Check` carrying the applied value, the
allowable, the resulting safety factor, and the formula as a string. The
formula string is rendered in the web report so a reader can follow the
reasoning rather than being asked to trust a number.

Units throughout: mm, N, MPa (= N/mm^2) — the same system as
:mod:`drone_demo.config`, chosen so no conversion factor is ever silently
missing. Frequencies and power convert to SI (m, kg, s) locally, where noted.
"""

from __future__ import annotations

import math
from dataclasses import dataclass

from drone_demo.config import LOAD_CASES, SPEC
from drone_demo.materials import material

_G = 9.80665  # m/s^2
#: Assembly torque used on every M3x12 structural bolt (matches the design
#: note in parts/arm.py — both must be changed together).
_ASSEMBLY_TORQUE_NM = 1.2
#: Nut factor for lightly lubricated steel into aluminium. Uncertain by
#: roughly +/-30%; every check that uses it says so in its note.
_NUT_FACTOR_K = 0.20
#: Friction coefficient, aluminium clamp on cured CFRP tube.
_FRICTION_MU = 0.15


@dataclass(frozen=True)
class Check:
    """One sizing calculation."""

    key: str
    title: str
    #: Human-readable formula, e.g. "sigma = M*c/I".
    formula: str
    #: Inputs, as name -> (value, unit), rendered as a table under the formula.
    inputs: dict[str, tuple[float, str]]
    applied: float
    allowable: float
    unit: str
    target_sf: float
    note: str = ""

    @property
    def safety_factor(self) -> float:
        return self.allowable / self.applied if self.applied > 0 else math.inf

    @property
    def passes(self) -> bool:
        return self.safety_factor >= self.target_sf


@dataclass(frozen=True)
class PerformanceReport:
    """Vehicle-level flight performance figures."""

    all_up_mass_g: float
    total_thrust_g: float
    thrust_to_weight: float
    #: Fraction of full thrust needed to hold a hover.
    hover_throttle: float
    #: Rough hover endurance from the usable battery energy, minutes.
    hover_endurance_min: float
    #: Disc loading, N/m^2 — the number that predicts how gusty-air stable it is.
    disc_loading_n_m2: float


def _load_case(key: str):
    for lc in LOAD_CASES:
        if lc.key == key:
            return lc
    raise KeyError(f"Unknown load case {key!r}")


def _thrust_per_motor_n(load_case_key: str, all_up_mass_g: float) -> float:
    """The reference thrust each motor carries under the named load case, in N.

    Hover and max-thrust are sized from different bases: hover is a quarter
    of whatever the vehicle actually masses (from the CAD), max-thrust is
    the motor's rated static thrust regardless of vehicle mass. Using the
    CAD-derived mass for hover — not the config target — is what lets this
    check catch a design that has grown heavier than intended.
    """
    if load_case_key == "hover":
        grams = all_up_mass_g / SPEC.airframe.arm_count
    elif load_case_key == "max_thrust":
        grams = SPEC.airframe.thrust_per_motor_g
    else:
        raise ValueError(f"{load_case_key!r} has no simple per-motor thrust basis")
    return grams / 1000.0 * _G


def performance() -> PerformanceReport:
    """Thrust-to-weight, hover throttle, endurance and disc loading.

    Endurance uses actuator-disk (momentum) theory rather than an assumed
    motor power rating, since none is given: ideal hover power per rotor is
    ``T^1.5 / sqrt(2*rho*A)``, divided by a figure of merit of 0.7 to account
    for real losses (tip losses, swirl, profile drag) that ideal momentum
    theory ignores. That FM is a generic small-multirotor figure, not
    measured for this propeller, so treat the endurance number as good to
    perhaps +/-20% — stated in the report, not left implicit.
    """
    from drone_demo.analysis.mass_properties import mass_report

    mass = mass_report()
    auw_g = mass.total_mass_g
    total_thrust_g = SPEC.airframe.thrust_per_motor_g * SPEC.airframe.arm_count
    thrust_to_weight = total_thrust_g / auw_g
    hover_throttle = auw_g / total_thrust_g

    rho = 1.225  # kg/m^3, sea level standard
    figure_of_merit = 0.7
    r_m = (SPEC.propeller.diameter_mm / 1000.0) / 2.0
    disc_area_m2 = math.pi * r_m**2
    hover_thrust_per_motor_n = (auw_g / SPEC.airframe.arm_count) / 1000.0 * _G

    p_ideal_w = hover_thrust_per_motor_n**1.5 / math.sqrt(2 * rho * disc_area_m2)
    p_hover_w = SPEC.airframe.arm_count * p_ideal_w / figure_of_merit

    pack_v = SPEC.battery.cells * SPEC.battery.nominal_v_per_cell
    usable_wh = SPEC.battery.capacity_mah / 1000.0 * pack_v * SPEC.battery.usable_fraction
    hover_endurance_min = usable_wh / p_hover_w * 60.0

    total_disc_area_m2 = SPEC.airframe.arm_count * disc_area_m2
    weight_n = auw_g / 1000.0 * _G
    disc_loading = weight_n / total_disc_area_m2

    return PerformanceReport(
        all_up_mass_g=auw_g,
        total_thrust_g=total_thrust_g,
        thrust_to_weight=thrust_to_weight,
        hover_throttle=hover_throttle,
        hover_endurance_min=hover_endurance_min,
        disc_loading_n_m2=disc_loading,
    )


def arm_root_bending(load_case: str) -> Check:
    """Bending stress in the arm tube at the clamp face.

    Cantilever: thrust ``F`` at the motor, root at the clamp face, so
    ``M = F * L``. Thin-walled tube: ``I = pi/64 * (D^4 - d^4)``,
    ``sigma = M * (D/2) / I``.

    ``L`` is the free tube length plus half the motor mount collar — the
    clamp does not restrain the tube perfectly at its face, and pretending
    it does under-predicts the moment.
    """
    from drone_demo.analysis.mass_properties import mass_report

    lc = _load_case(load_case)
    t = SPEC.arm_tube
    mat = material("cfrp_tube")
    auw_g = mass_report().total_mass_g

    f_n = _thrust_per_motor_n(load_case, auw_g)
    length_mm = t.length_mm + SPEC.motor_mount.collar_length_mm / 2.0
    moment = f_n * length_mm
    i_mm4 = (math.pi / 64) * (t.outer_dia_mm**4 - t.inner_dia_mm**4)
    sigma = moment * (t.outer_dia_mm / 2) / i_mm4

    return Check(
        key=f"arm_root_bending_{load_case}",
        title=f"Arm tube root bending — {lc.title}",
        formula="sigma = M*c/I,  M = F*L,  I = pi/64*(D^4-d^4)",
        inputs={
            "F": (f_n, "N"), "L": (length_mm, "mm"),
            "D": (t.outer_dia_mm, "mm"), "d": (t.inner_dia_mm, "mm"),
        },
        applied=sigma,
        allowable=mat.yield_mpa,
        unit="MPa",
        target_sf=lc.target_sf,
        note=(
            "Allowable is the CFRP's ultimate axial strength, not a yield "
            "point — the material is brittle, so there is no useful yield."
        ),
    )
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
